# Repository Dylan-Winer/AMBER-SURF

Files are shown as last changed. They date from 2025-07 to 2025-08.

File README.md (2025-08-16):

# AMBER-SURF
Repository hosting project files as part of my Summer Undergraduate Research Fellowship (SURF) 2025 project within the AMBER Lab at Caltech.

## Mechanical Components & Assembly

This section covers the physical build of the foot modules and begins exactly where the right-foot assembly was left off.

---

### Complete the Right Foot: Rubber Sole & Adhesive Nuts

1. **Get the sole DXF**
   - Download `sole_base.DXF` from this repo:  
     https://github.com/Dylan-Winer/AMBER-SURF/blob/main/SolidWorks-CAD/G1_Integration/DXF_G1_3/sole_base.DXF

2. **Cut the rubber sole**
   - Acquire **1/8" thick rubber** sheet.
   - **Waterjet** cut the sole using `sole_base.DXF`. Deburr/trim if needed for a clean perimeter.

3. **Bolt the remaining hardware**
   - From the bag labeled **“4/40 BOLTS & SPACERS”**, locate the **four remaining adhesive nuts**, **4-40 bolts**, and **spacers**.
   - Install these in the positions on the **right foot** where bolts are currently missing. Snug the 4-40 bolts; don’t over-torque.
   - There are through-holes cut into the cable channels on both the heel connectors. Use these to fit an allen key through. You may need to push the cables out of the way with the allen key.

4. **Bond the adhesive nuts to the rubber**
   - Remove the rubber sole; place a small, even bead of **Gorilla Glue** *or* a suitable **epoxy** on the **underside of all 8 adhesive nuts**.
   - Press the **waterjet rubber sole** onto the adhesive nuts with **even pressure**. Using a **vise** to hold the foot makes this easier; protect surfaces with scrap pads.
   - **Cure per adhesive instructions.** (If using Gorilla Glue, lightly dampen the rubber for proper foaming; for epoxy, degrease both surfaces first.)

5. **Prep for base plate + toe installation**
   - **Unscrew** the four **4-40 bolts & spacers** that mount the **heel connector** to the foot so the **right foot matches the left**.
   - The **heel must come off** so the **base plate and toe** can be **slid on from the front**.

> ✅ Quick checklist  
> - [ ] Rubber sole waterjet and is clean  
> - [ ] All 8 adhesive nuts bonded and cured  
> - [ ] Heel connector hardware removed (right foot)  
> - [ ] Fit check: base plate + toe can slide on from the front

---

### Install Each Module (Left & Right Feet)

1. **Slide-on fit**
   - **Slip the G1 foot** through the **toe cover** until the bottom of the G1 foot is **fully seated** on the **top of the bottom base plate**.
   - Verify the **toe and heel bumpers** **fully enclose** the foot with uniform contact.

2. **Reinstall heel hardware**
   - Cover the heel of the G1 with the **heel mounts**.
   - **Screw the four 4-40 bolts + spacers** into the **four heel-mount holes**. Tighten evenly in a cross pattern until snug.

3. **Cable & strain relief**
   - Route cables cleanly along edges and through any provided channels. Add **strain relief** (zip ties/adhesive anchors) to protect connectors and solder joints.

4. **USB to host**
   - Connect **micro-USB** from **each foot module** to the computer. In practice you’ll likely use **USB extension cables** plus **90° micro-USB cables** to keep a low profile.

5. **Proceed to logging**
   - Follow the **Arduino/CoolTerm** instructions in the previous section to set **per-foot baud rates** and **capture data**.

# AMBER Lab SURF 2025 — G1 Foot Sensing Module

High-rate (1000 Hz) force + IMU logging for the Unitree G1 humanoid foot.  
The following contains Teensy 4.1 usage notes to capture synchronized FSR forces and MPU-6050 orientation/gyro data to CSV via CoolTerm.

---

## TL;DR (How to run & log)

1. **Install & open CoolTerm.**
2. **Connect the Teensy (USB).**
3. In CoolTerm: **Connection → Options…**
   - **Port:** select the COM port associated with your Teensy.
   - **Baudrate:** set to the same value used in firmware `Serial.begin(BAUDRATE)` (defaults shown in the code below are `2,000,000`).
   - Click **OK**.
4. Click **Connect**.
5. Start file logging: **Connection → File Capture → Start…**
   - Choose a folder, **create/name a `.txt` file**, click **Save**.
6. In the CoolTerm terminal, press **`s`** to **start** the program (CSV header prints once).
7. **Run your G1 test** (walk/stance as needed).
8. Press **`x`** to **stop** the program.
9. Stop file logging: **Connection → File Capture → Stop**.

> **Left vs Right foot**  
> You will run **two Teensies** (left/right) at **different baud rates** to avoid USB bandwidth contention and to keep ports distinct.  
> - Edit `Serial.begin(BAUDRATE)` in each foot’s firmware (e.g., Left `2,000,000`, Right `1,500,000`).  
> - In CoolTerm, pick the matching COM port and set the **Baudrate** accordingly for each run.

---

## Data format (CSV columns)

When logging is active, the firmware prints:
time_s,FSR1_N,FSR2_N,FSR3_N,FSR4_N,qw,qx,qy,qz,gx_rad_s,gy_rad_s,gz_rad_s

- **time_s** — seconds since you pressed `s`
- **FSR*_N** — force in Newtons after per-sensor linear calibration and dead-zone/zero-clipping (<2 N → 0)
- **qw..qz** — unit quaternion from Mahony filter
- **g*_rad_s** — body-frame gyro rates (rad/s) derived from RAW with offsets & scale

---

## Hardware overview

- **Controller:** Teensy 4.1 (3.3 V logic)
- **FSRs:** 4× FlexiForce A201 (per-sensor linear calibration applied)
- **IMU:** MPU-6050
- **Loop rate:** 1000 Hz fixed tick (1 ms)

---

## Build & Flash (Teensy 4.x)

1. Open this repo’s firmware in **Arduino IDE** or **Arduino CLI** with **Teensyduino** installed.
2. Select **Board: Teensy 4.0/4.1** and the correct **Port**.
3. (Optional) Adjust:
   - `Serial.begin(BAUDRATE)` for your left/right feet.
   - FSR calibration `slope[]` and `intercept[]`.
   - Mahony gains `Kp`, `Ki`.
4. **Upload**.

## 3) Analyze Data (Python)

Program link (full script):  
**➡️ https://github.com/Dylan-Winer/AMBER-SURF/blob/main/Python_Code/G1_Data_Analysis/Force_Plot_Final.py**

**Use it like this:**
- Replace `file_path` with your CoolTerm **.txt/.csv** path.
- Set `t_start_s` and `t_end_s` (easiest way to focus on a window; set `0` to analyze everything).
- Run the script to get **plots** and **replay videos** (MP4 if FFmpeg available; otherwise GIF).
- Don’t need outputs? Comment out the plot sections and/or the `make_replay_video(...)` calls.

**Expected columns** in the file:
time_s,FSR1_N,FSR2_N,FSR3_N,FSR4_N,qw,qx,qy,qz,gx_rad_s,gy_rad_s,gz_rad_s

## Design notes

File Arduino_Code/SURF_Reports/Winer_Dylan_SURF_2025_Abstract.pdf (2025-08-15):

Toward Contact-Aware Humanoid Locomotion: A Modular Foot Sensing Platform Dylan Winer
Mentors: Aaron Ames, Sergio Esteban, and Adrian Ghansah

Stable locomotion in humanoid robots requires accurate knowledge of foot-ground interaction forces, yet existing systems often lack integrated, distributed foot sensing and typically rely on flat, rigid feet that omit the heel-toe rolling found in human gait. To address this, we developed a modular sensing platform with a passive toe mechanism for a new humanoid robot in the AMBER Lab. The system integrates FlexiForce™ force-sensitive resistors (FSRs) amplified through non-inverting op-amp circuits, inertial measurement units (IMUs), and magnetic encoders. Each FSR is individually calibrated to linearly interpolate force from analog voltage output. A custom 4-layer PCB interfaces with a Teensy 4.1 microcontroller, supporting analog readout, 16 status LEDs, dual IMU input, and a PWM-based encoder for passive toe angle measurement. The standalone mechanical design includes toe and midfoot segments, torsional spring toe actuation, a waterjet-cut rubber sole, and helical insert fasteners. All components are mounted to a modular foot structure appended to the Unitree G1 humanoid for initial testing. Final integration will enable measurement of distributed ground reaction forces, segment orientations, and joint angles during walking. This modular platform offers a scalable foundation for contact-aware control to improve future humanoid locomotion and manipulation.

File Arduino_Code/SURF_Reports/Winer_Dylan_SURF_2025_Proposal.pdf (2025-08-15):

SURF 2025 Proposal: Improving Humanoid Locomotion via Advanced Foot Sensing

Introduction/Background

This research project investigates the enhancement of bipedal robot locomotion by incorporating multi-contact foot behavior through the advancement of foot sensing capabilities. Current limitations in bipedal robotics, such as restricted agility and efficiency, stem from simplified models that often neglect the nuanced dynamics of human walking, which involve multi-contact interactions between the foot and the ground (e.g., heel-toe rolling). This research addresses these limitations by drawing inspiration from human locomotion and developing novel control strategies that enable more natural and dynamic walking behavior.

Building upon the research conducted by Professor Ames and his group in the AMBER Lab, which has established a strong foundation in developing control strategies for bipedal robots using reduced-order models and hybrid systems theory, this project will explore how integrating more advanced foot sensors can improve model accuracy and enable more dynamic, human-like gait transitions. Specifically, various sensors of interest will be investigated, the existing foot design will be modified to integrate these sensors, and their impact on locomotion performance will be validated. The successful implementation of these advancements will lead to significant improvements in the stability, efficiency, and robustness of bipedal robots, with potential applications in humanoid assistance, disaster relief, and space exploration.

Objectives

This project aims to improve humanoid locomotion by integrating advanced foot sensing, enabling more natural and efficient multi-contact walking. To achieve this, ground reaction forces, contact locations, and foot orientation among others will be measured using pressure sensors, inertial measurement units (IMUs), capacitive sensors, and various others under diverse walking conditions. The starting assumption is that the current humanoid robot has a rigid foot featuring toe and ankle mechanisms without sensing capabilities, limiting its ability to adapt to uneven terrain and dynamic motion. A successful outcome will involve designing and implementing a novel foot structure that seamlessly integrates these sensors; developing a data-driven model of multi-contact foot behavior utilizing sensor data collected from the robot; integrating sensor feedback into a control framework to adapt robot behavior in real-time based on observed interactions; and evaluating the enhanced robot’s performance through metrics such as energy consumption, step length, and robustness to perturbations. Success will be determined by the effective integration and validation of the sensors, the accuracy of the foot behavior model, and demonstrated improvements in robotic locomotion.

Approach

To accomplish the project objectives, a structured, 10-week approach will be followed inspired by previous research in bipedal robotics, with key milestones outlined below:

1. Sensor Exploration (Weeks 1-2): Various sensors—pressure sensors, IMUs, capacitive sensors, and more—will be experimented with to understand their behavior and how to best integrate them into the foot. This hands-on exploration will inform the selection and analysis methods for each sensor type.
2. Mechanical Design (Weeks 3-4): The foot design will be modeled and modified in SolidWorks® to integrate the chosen sensors. This process will ensure the foot can support multi-contact interactions, enabling more advanced locomotion than flat-foot sensing.
3. Sensor Integration (Weeks 5-7): The selected sensors will be integrated into the foot structure, focusing on ensuring accurate measurements of foot-ground interactions, allowing for state-of-the-art motion including stair climbing and running.
4. Performance Validation (Weeks 8-9): The robot will undergo a series of tests to evaluate the effectiveness of the sensor-integrated foot. These tests will assess the foot’s ability to adapt to different terrain conditions and its overall locomotion capabilities.
5. Evaluation and Adjustments (Week 10): In the final week, the foot’s performance will be thoroughly assessed, and any necessary adjustments will be made to optimize its functionality, ensuring it is capable of humanoid and dynamic motion.

Sensor integration will be particularly challenging due to the diverse signal types from different sensors, requiring careful calibration and data fusion. To address this, insights will be leveraged from the LIDAR Lab and Professor Zhao’s work on multi-modal contact sensing and terrain classification to optimize sensor selection and data processing strategies. Sergio Esteban, serving as the project mentor, will be consulted along with other AMBER Lab students to refine the integration process and troubleshoot issues collaboratively. The basic foot and humanoid robot will be inherited from the lab, but sensors, testing equipment, and facilities will be needed to measure the foot’s effectiveness. For example, an Instron machine may be utilized to cyclically assess the sensor-equipped foot during validation testing. An Arduino or similar platform will be utilized for sensor integration and software like Simulink will be used for foot and sensor control. The role will involve collaboration with Adrian Ghansah, who is focused on the development of 3D humanoid robots. This project’s completion will not depend on others, but the overall integration and validation of the robot will rely on progress from two students overseeing structural analysis and manufacturability.

Work Plan

Task | Start Date | End Date
Sensor Exploration | Week 1 | Week 2
Mechanical Design | Week 3 | Week 4
Sensor Integration | Week 5 | Week 7
Performance Validation | Week 8 | Week 9
Evaluation and Adjustments | Week 10 | Week 10
Final Technical Paper & Presentation | To be determined | Week 10

References

[1] X. Guo et al., “Soft Foot Sensor Design and Terrain Classification for Dynamic Legged Locomotion,” IEEE International Conference on Soft Robotics (RoboSoft), pp. 550–557, May 2020, doi: https://doi.org/10.1109/robosoft48309.2020.9115990.
[2] T. Tyler, V. Malhotra, A. Montague, Z. Zhao, F. L. Hammond, and Y. Zhao, “Integrating Reconfigurable Foot Design, Multi-modal Contact Sensing, and Terrain Classification for Bipedal Locomotion,” IFAC-PapersOnLine, vol. 56, no. 3, pp. 523–528, 2023, doi: https://doi.org/10.1016/j.ifacol.2023.12.077.
[3] M. Dai, J. Lee, and A. D. Ames, “Multi-Domain Walking with Reduced-Order Models of Locomotion,” 2022 American Control Conference (ACC), pp. 2830–2837, Jul. 2024, doi: https://doi.org/10.23919/acc60939.2024.10644270.
[4] H. Zhao, A. Hereid, W. Ma, and A. D. Ames, “Multi-contact bipedal robotic locomotion,” Robotica, vol. 35, no. 5, pp. 1072–1106, Dec. 2015, doi: https://doi.org/10.1017/s0263574715000995.

Discussions with AMBER Lab PhD students Adrian Ghansah and Sergio Esteban emphasized that every biomechanical example of locomotion relies on foot sensing for stability and adaptability, but current systems operate with limited sensing capabilities. Their insights on ongoing efforts, including the development of a new bipedal robot with a dedicated toe mechanism, informed the direction of this project.

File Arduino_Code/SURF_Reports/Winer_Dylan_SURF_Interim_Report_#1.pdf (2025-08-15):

Winer 1

Researcher: Dylan Winer

PI: Professor Aaron Ames

Mentor: Sergio Esteban

Date: June 27, 2025

SURF 2025 Interim Report #1

Motivation and Background
Understanding the ground reaction forces and moments at a humanoid robot's foot is essential for achieving robust, adaptable, and dynamically stable locomotion across varied terrains. This information enables control algorithms to react appropriately to foot-ground interactions, such as uneven loading between heel and toe or early loss of contact during a step. My project focuses on the development of a modular tactile sensing foot that can quantify such force distributions during walking. The long-term goal is to develop a lightweight, low-cost, replaceable sensor module that outputs real-time tactile data, contributing to the broader
AMBER Lab initiative of designing a full humanoid robot platform by the end of the summer. This work ties into the broader research within the AMBER Lab, which investigates hybrid systems theory and optimization-based control for robotic locomotion [1, 2]. Previous work has demonstrated that ground contact forces, represented as external reaction terms λ in the Lagrangian formulation, play a central role in multi-domain bipedal walking models [2]. Several prior sensor designs have been proposed to estimate these forces, including MEMS barometric sensor arrays [3], multimodal contact sensing with reconfigurable feet [4, 5], and integrated force-torque sensors [6]. These systems inspire the sensing strategies explored in this project.

Problem and Methods
The core problem is designing and integrating a sensor system that can estimate spatially distributed ground forces under the foot while remaining modular, affordable, and lightweight. Commercial force-torque sensors and pressure mats are often prohibitively expensive or unfit for onboard integration. Therefore, our approach is to prototype with Force-Sensitive Resistors (FSRs) and mechanical push buttons due to their simplicity, availability, and ease of integration. While these sensors have limitations in accuracy and drift, they offer a scalable platform for preliminary force localization, edge detection, and binary contact confirmation.
We are exploring multiple sensing modalities: barometric pressure sensors for distributed sensing, FSRs for localized force detection, and rugged push buttons for binary heel/toe contact validation. The system is being prototyped using a Teensy 4.0 microcontroller and inverting op-amp circuits for signal conditioning. Our initial integration pathway uses analog inputs and voltage dividers, with plans to transition to multiplexed digital buses (e.g., I²C or CAN) for final integration into the robot. In parallel, we are developing a custom PCB using KiCAD and JLCPCB manufacturing constraints to create a robust, soldered version of the prototype circuit. Mechanically, the sensors are being embedded into a multilayer sole that includes silicone rubber for load distribution and protection, with manufacturer-provided pucks to concentrate forces.

Progress
Significant progress has been made across sensor selection, prototyping, mechanical design, and PCB development. We began with a review of prior foot sensor integrations, including MEMS barometers, FSRs, and six-axis force/torque sensors. We then prototyped a voltage divider circuit using Interlink FSR 406 sensors and calibrated the force-resistance relationship through known loads (Figures 1-2). The derived relationship followed a log-log
trend: | (Figure 3), enabling real-time force estimation from analog readings.
These signals were visually validated with LEDs and displayed on Arduino IDE’s plotter.
| We created CAD models of the force sensors, load concentrator pucks, and a multilayer
foot assembly that includes recesses and cable routing (Figures 4-9). For binary detection, we wired pushbuttons to Teensy pins and assessed their behavior under simulated footfalls. Additionally, we explored edge detection by taping FSR strips to the front and rear of a Unitree G1 Humanoid robot foot (Figure 10), confirming that 1 N was a reasonable threshold for contact events. We then designed a two-FSR PCB prototype in KiCAD with surface-mounted LEDs for feedback, Teensy header footprints, resistors, and analog input wiring (Figures 11-15). We then created the manufacturing files in accordance with JLCPCB constraints. Finally, we designed a passive toe mechanism for enhanced contact area, referencing both previous AMBER designs and published work (Figures 16-17). The front toe segment rotates about a shaft constrained radially by two bushings and axially by shaft collars. A 120° torsional spring provides the restoring moment. It remains preloaded to ensure the two segments are parallel while the toe is not activated. All 3D prints have been fabricated and parts ordered for initial assembly.

Challenges and Anticipated Problems
| One major challenge is the high cost and limited modularity of commercial force-torque
sensors. Many high-performance options cost $3,000–$10,000 and must be installed at the ankle, complicating direct foot sensing. Similarly, commercial pressure mats from AMTI or Kistler are prohibitively expensive for long-term use, though we identified an affordable $400 force plate from Vernier for validation purposes, which we may pursue further.
| Another challenge involves the complexity of custom MEMS barometer sensors. These
require delicate mechanical modifications, vacuum-cast encapsulation, and custom PCB designs with multiplexers. While promising, these systems demand greater resources and will be explored later in the project. PCB design also presented difficulties, as we initially began in Autodesk Eagle before switching to KiCAD due to future deprecation. Learning KiCAD workflows, adhering to JLCPCB manufacturing rules, and generating valid Gerber files required careful attention. The prototype PCB will be soldered and evaluated in the coming week.
| Moving forward, we anticipate challenges in validating the sensor outputs against known
force data, especially under dynamic walking conditions. Signal noise, mechanical stress shielding, and sensor drift may also introduce errors. However, our modular design approach and layered validation strategy, using both internal sensors and potentially an external plate, position us well to continue iterating toward a deployable foot module.

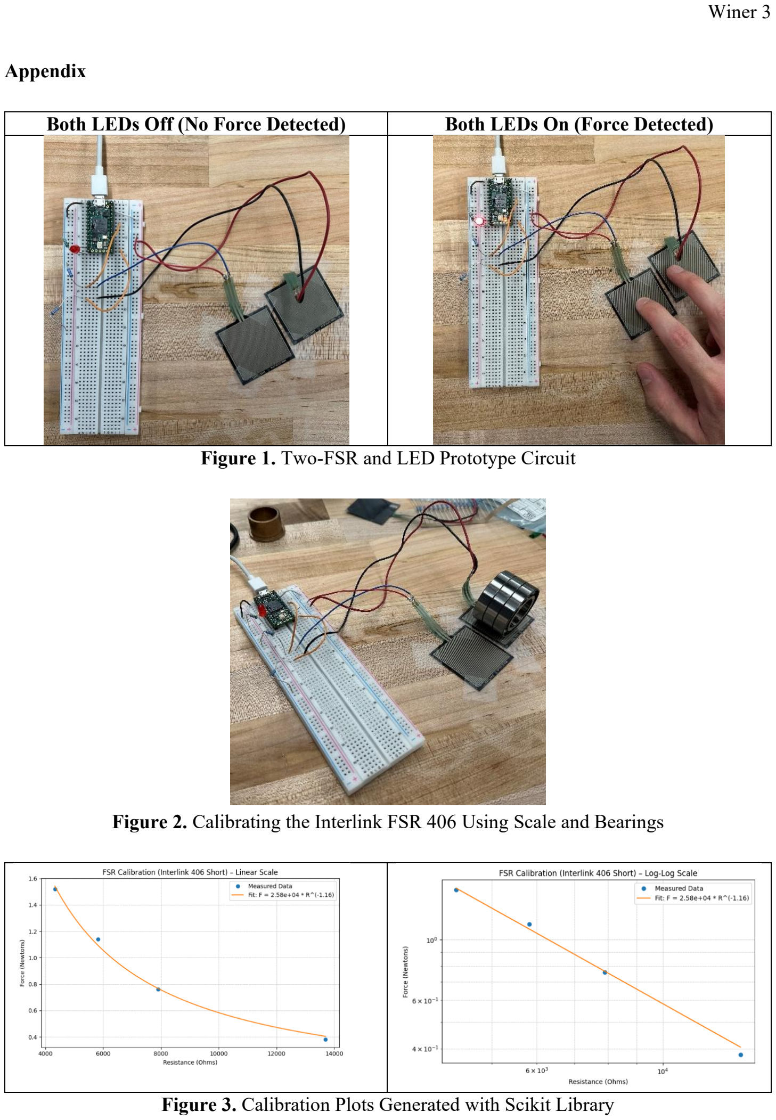
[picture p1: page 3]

Appendix

Both LEDs Off (No Force Detected) | Both LEDs On (Force Detected)

Figure 1. Two-FSR and LED Prototype Circuit

Figure 2. Calibrating the Interlink FSR 406 Using Scale and Bearings

Figure 3. Calibration Plots Generated with Scikit Library

Figure 4. CAD Model of FlexiForce A201 Sensor

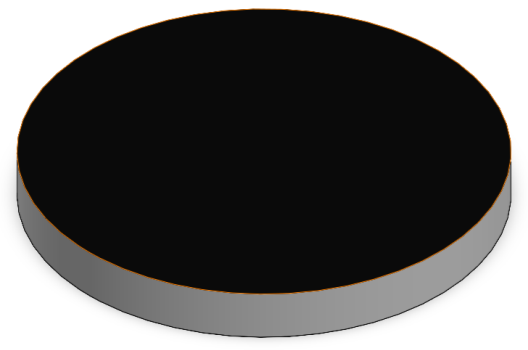
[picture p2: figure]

Figure 5. CAD Model of FLXLC-A Puck for A201 Sensor

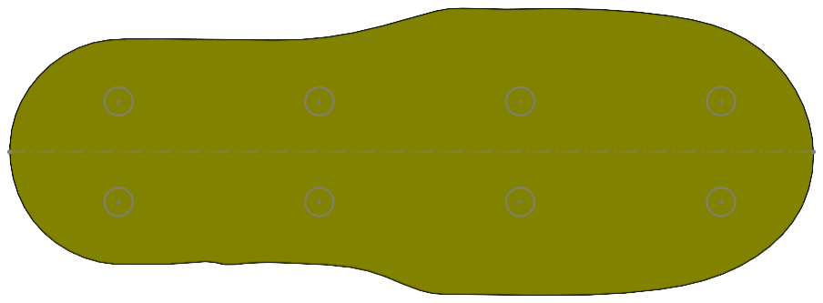
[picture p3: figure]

Figure 6. CAD Model of Top of Preliminary Sensing Module Assembly

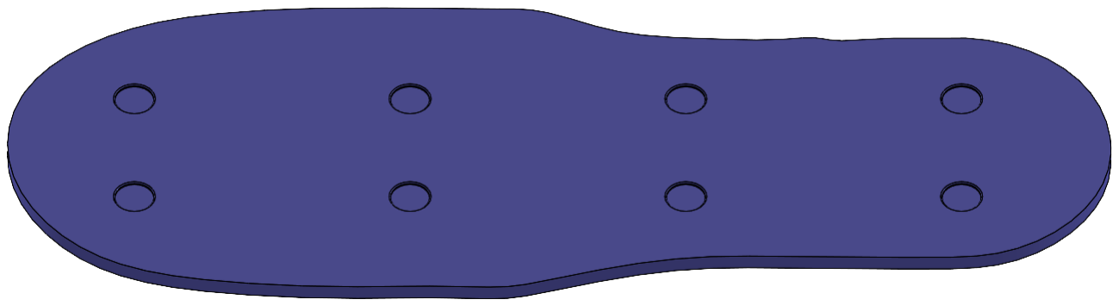
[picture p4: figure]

Figure 7. CAD Model of Bottom of Preliminary Sensing Module Assembly

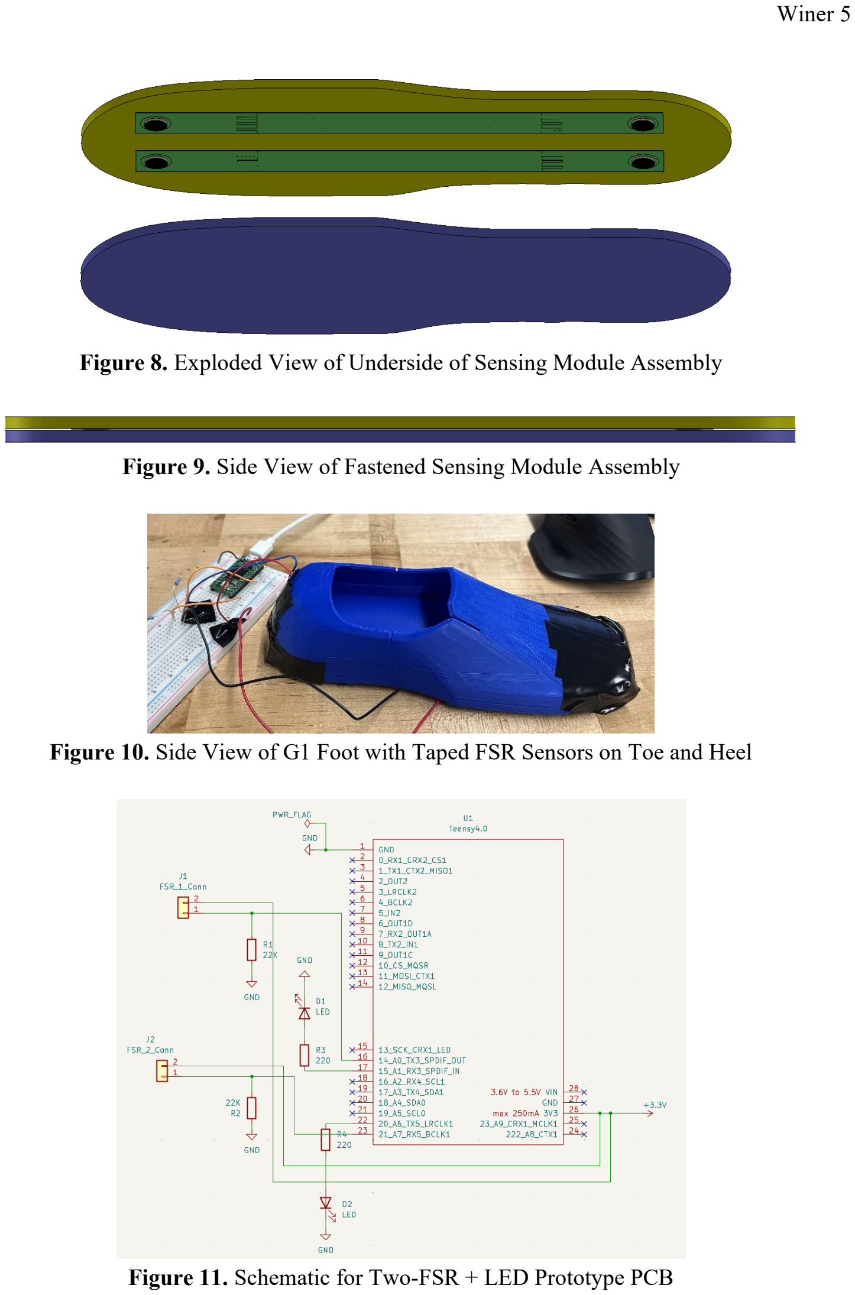
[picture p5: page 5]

Figure 8. Exploded View of Underside of Sensing Module Assembly

Figure 9. Side View of Fastened Sensing Module Assembly

Figure 10. Side View of G1 Foot with Taped FSR Sensors on Toe and Heel

Figure 11. Schematic for Two-FSR + LED Prototype PCB

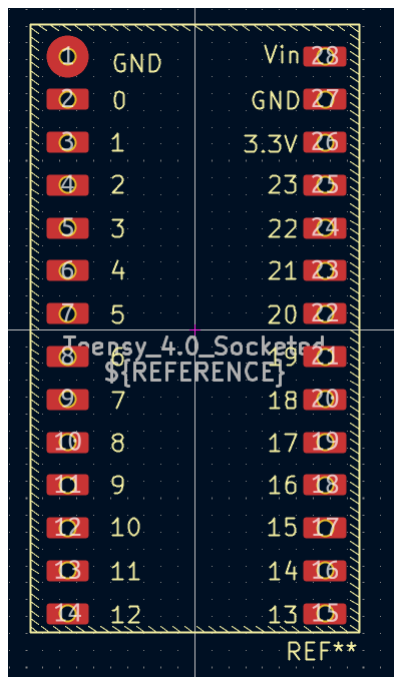
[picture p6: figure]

Figure 12. Custom Footprint Created for Teensy Through-Holes

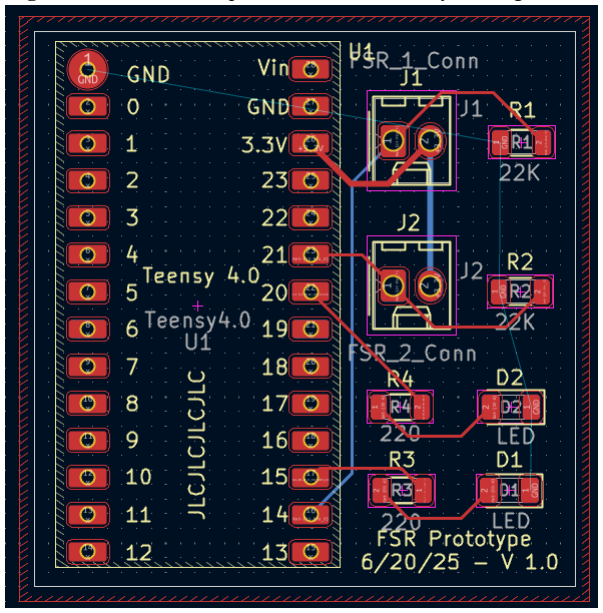
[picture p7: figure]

Figure 13. FSR Prototype PCB Sketch with Traces and Components

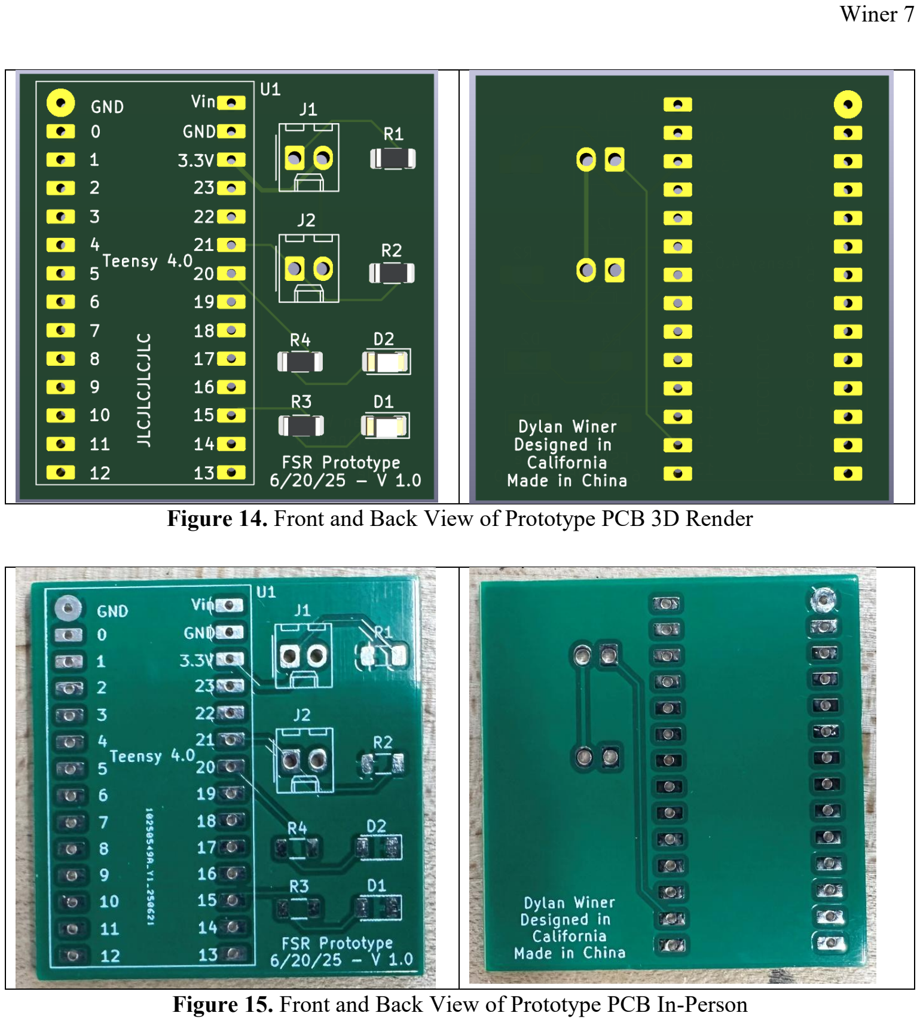
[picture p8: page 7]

Figure 14. Front and Back View of Prototype PCB 3D Render

Figure 15. Front and Back View of Prototype PCB In-Person

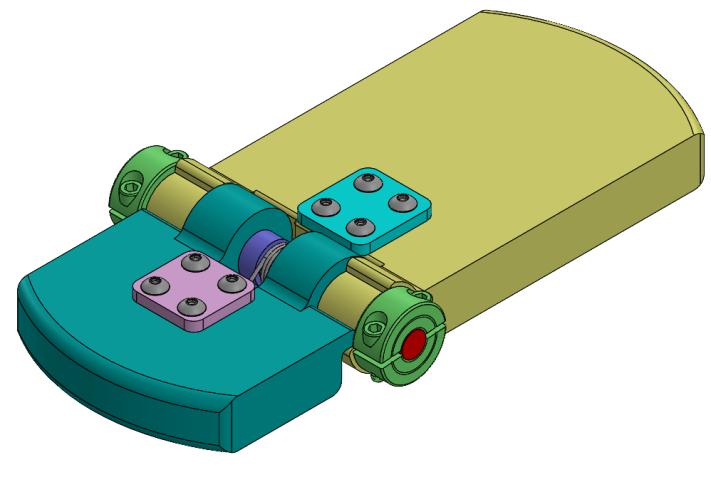
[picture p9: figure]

Figure 16. Isometric View of Prototype Passive Toe Assembly

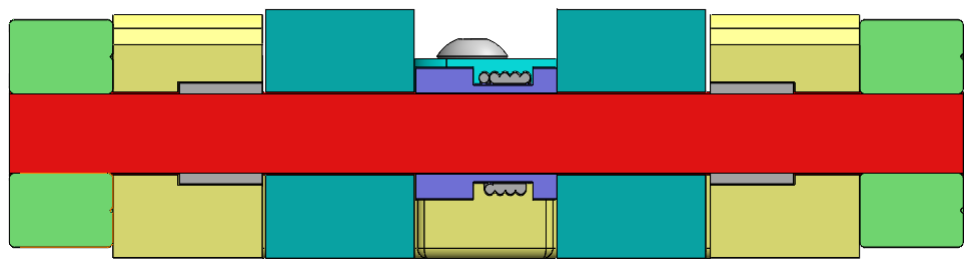
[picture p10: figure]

Figure 17. Cross-Section View of Center Shaft, Segments, Bushings, and Spring

References

[1] M. Dai, J. Lee, and A. D. Ames, “Multi-Domain Walking with Reduced-Order Models of Locomotion,” 2022 American Control Conference (ACC), pp. 2830–2837, Jul. 2024, doi: https://doi.org/10.23919/acc60939.2024.10644270.
[2] H. Zhao, A. Hereid, W. Ma, and A. D. Ames, “Multi-contact bipedal robotic locomotion,” Robotica, vol. 35, no. 5, pp. 1072–1106, Dec. 2015, doi: https://doi.org/10.1017/s0263574715000995.
[3] X. Guo et al., “Soft Foot Sensor Design and Terrain Classification for Dynamic Legged Locomotion,” pp. 550–557, May 2020, doi: https://doi.org/10.1109/robosoft48309.2020.9115990.
[4] T. Tyler, V. Malhotra, A. Montague, Z. Zhao, F. L. Hammond III, and Y. Zhao, “Integrating Reconfigurable Foot Design, Multi-modal Contact Sensing, and Terrain Classification for Bipedal Locomotion,” IFAC-PapersOnLine, vol. 56, no. 3, pp. 523–528, 2023, doi: https://doi.org/10.1016/j.ifacol.2023.12.077.
[5] Risto Koiva, T. Schwank, G. Walck, M. Meier, R. Haschke, and H. Ritter, “Barometer-based Tactile Skin for Anthropomorphic Robot Hand,” Oct. 2020, doi: https://doi.org/10.1109/iros45743.2020.9341691.
[6] K. Fondahl et al., “An adaptive sensor foot for a bipedal and quadrupedal robot,” Jun. 2012, doi: https://doi.org/10.1109/biorob.2012.6290735.

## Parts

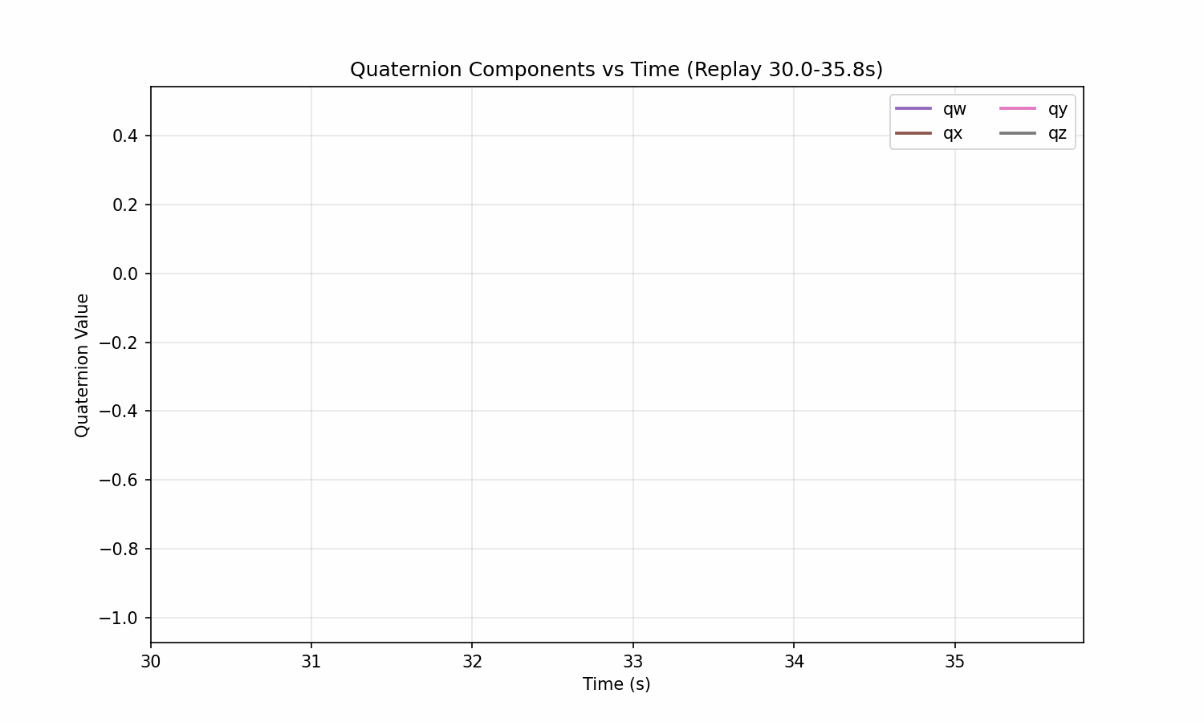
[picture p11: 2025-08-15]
Python_Code/G1_Data_Analysis/G1-Post_Animations/30_35-8_seconds/quaternion_components_replay_30.0-35.8s.gif

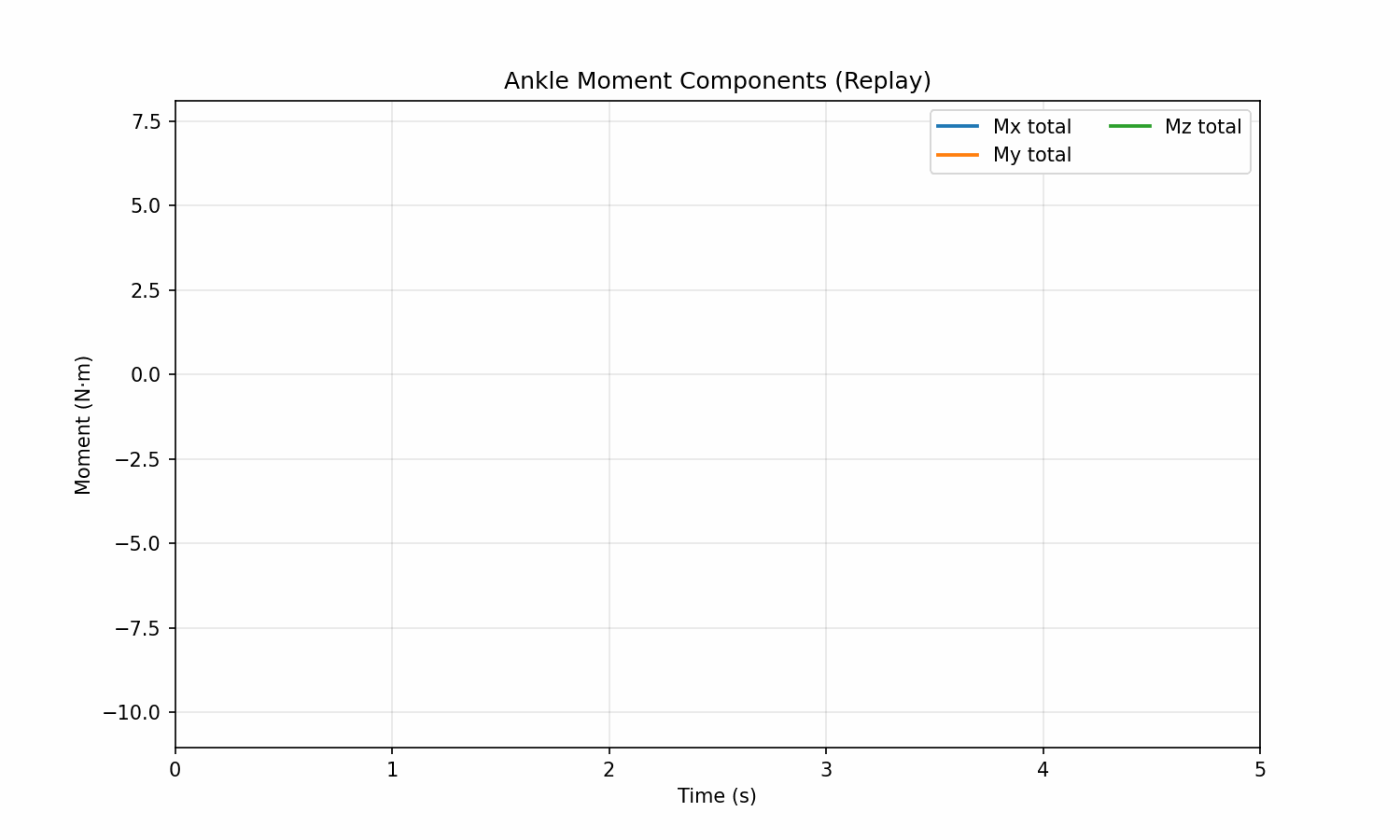
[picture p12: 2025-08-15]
Python_Code/G1_Data_Analysis/G1-Post_Animations/0_5_seconds/moments_components_replay.gif

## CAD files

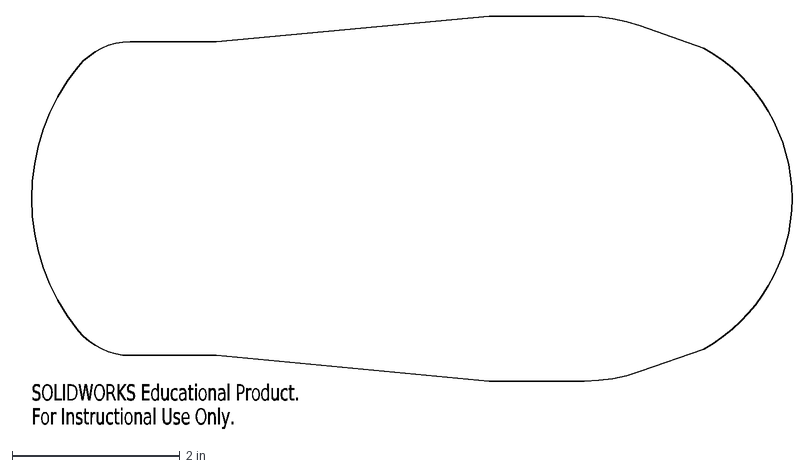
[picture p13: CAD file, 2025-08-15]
SolidWorks-CAD/G1_Integration/DXF_G1_3/sole_base.DXF
SOLIDWORKS Educational Product.
For Instructional Use Only.

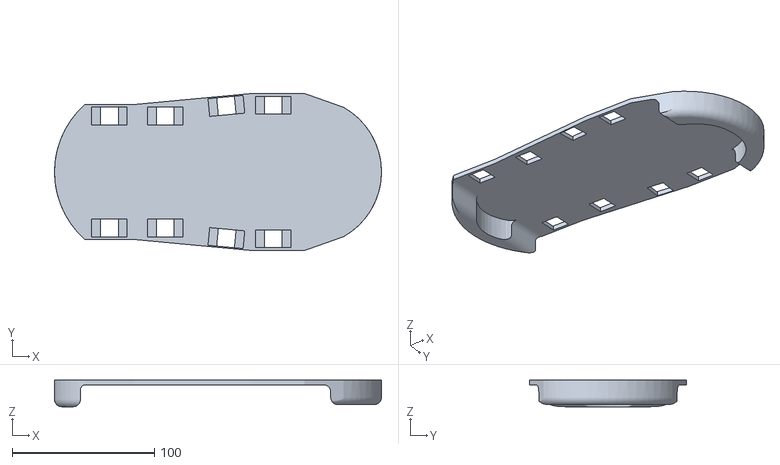
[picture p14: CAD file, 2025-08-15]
SolidWorks-CAD/G1_Integration/G1_2/sole_mid_V2.STL
230.2 x 110.5 x 18.7

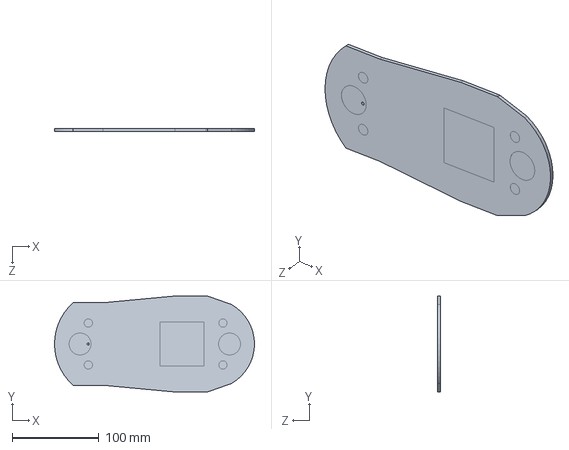
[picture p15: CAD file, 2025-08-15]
SolidWorks-CAD/G1_Integration/G1_Dylan_Pack_And_Go/sole_base.SLDPRT
230.2 x 110.5 x 3.18 mm

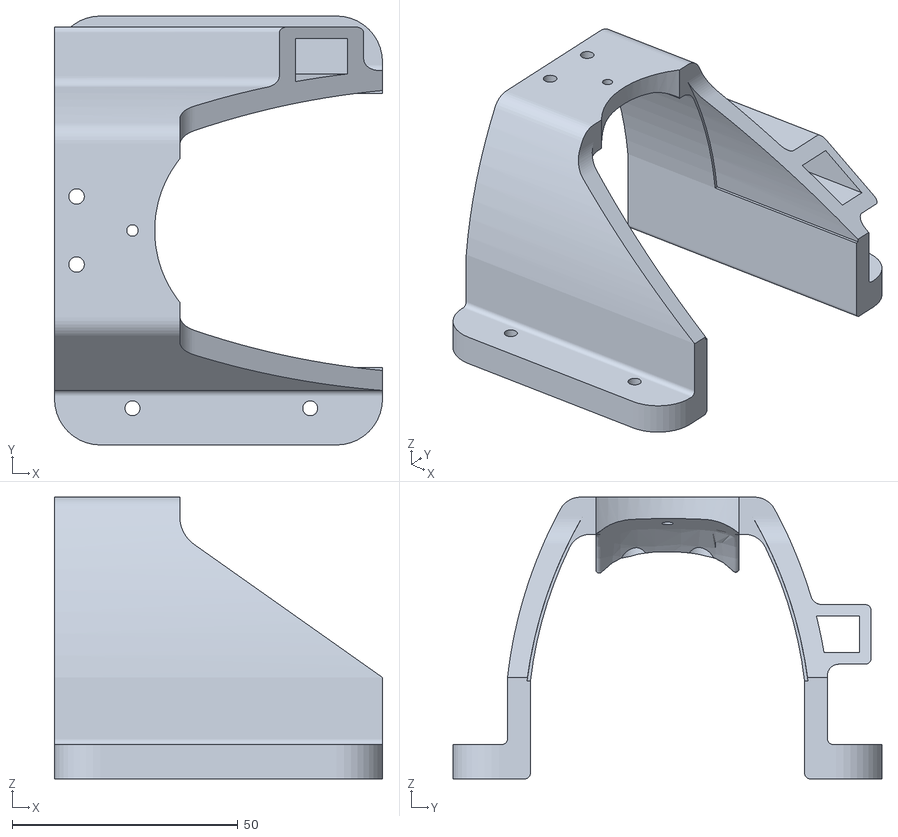
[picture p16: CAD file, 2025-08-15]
SolidWorks-CAD/G1_Integration/STLS_G1_1/mid-back.STL
72.6 x 95.0 x 62.4

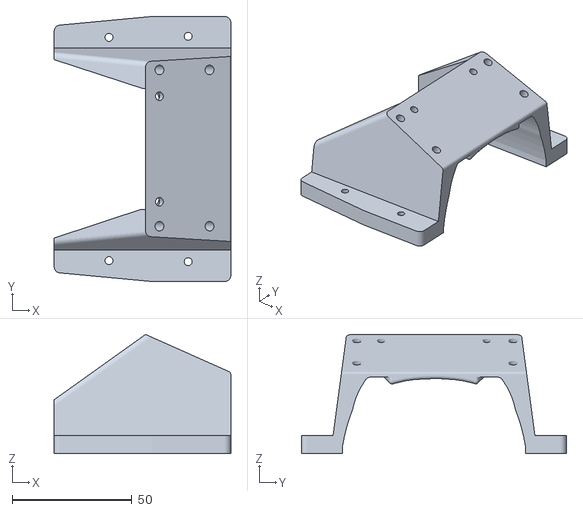
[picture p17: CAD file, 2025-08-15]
SolidWorks-CAD/G1_Integration/STLS_G1_3/mid-front-right.STL
73.7 x 110.5 x 49.7

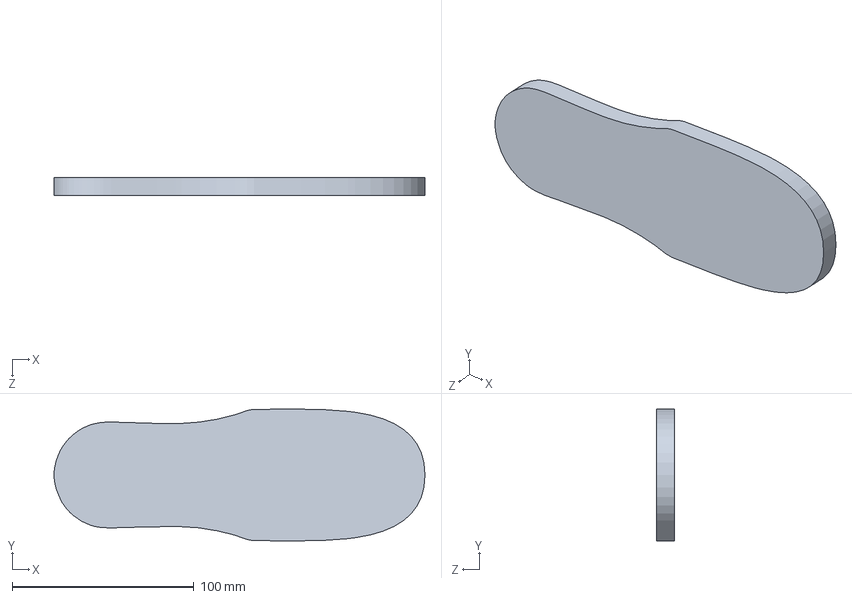
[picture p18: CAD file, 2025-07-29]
SolidWorks-CAD/Prototype1/Thicken1.SLDPRT
204.3 x 72.5 x 9.86 mm

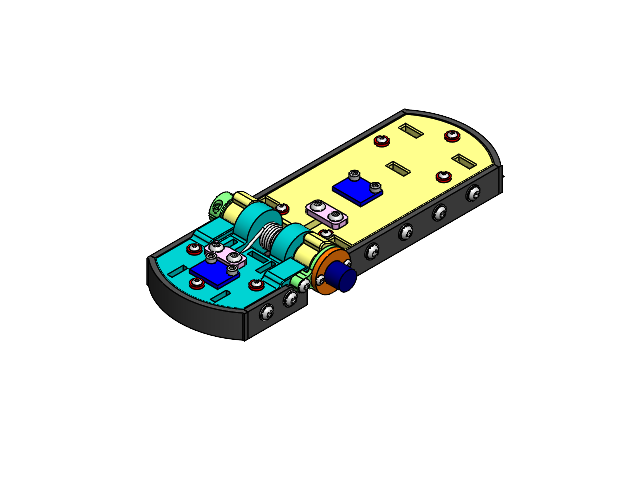
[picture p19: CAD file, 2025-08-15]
SolidWorks-CAD/Toe_Prototype_2/Passive_Toe_2.SLDASM
Heel_Midfoot_2
Shaft_2
Toe_Segment_2
6436K32_Clamping Two-Piece Shaft Collar
2867T41_Corrosion-Resistant Sleeve Bearing x 2
9271K641_Torsion Spring
Spring_Sleeve_2
Top-Plate-Midfoot_2-2
Toe_Rubber
Heel_Midfoot_Rubber
A201_2 x 4
FLXLC-A x 8
93512A110_Stainless Steel Narrow-Base Adhesive-Ready Nuts x 8
A502
A401 x 2
A401_Puck x 2
A502_Puck
Top-Plate-Heel_2-2
SideRubberToe
SideRubberToeOG
FrontBackRubber x 2
SideRubberHeel
SideRubberHeelEnc
91732A656_Stainless Steel Helical Insert x 17
92095A192_Button Head Hex Drive Screw x 17
Spacer1 x 6
Spacer2 x 2
92949A811_18-8 Stainless Steel Button Head Hex Drive Screw x 8
93475A230_18-8 Stainless Steel Washer x 12
magnet_hub
base_mount
base
90593A001_Black-Oxide Steel Hex Nut x 6
92095A181_Button Head Hex Drive Screw x 2
MPU-6050 x 2
91290A115_Alloy Steel Socket Head Screw x 4

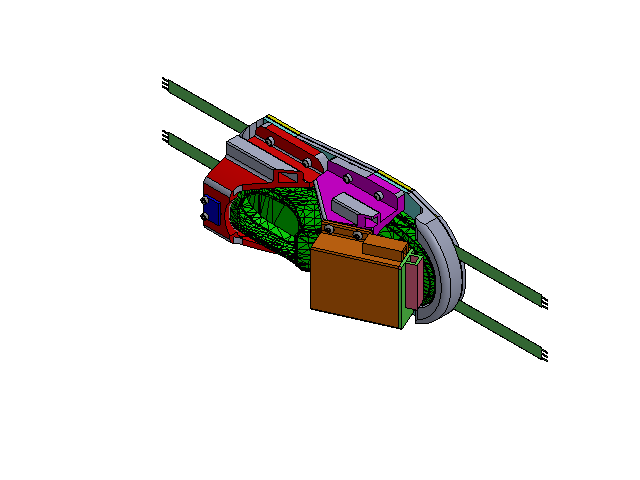
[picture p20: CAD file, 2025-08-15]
SolidWorks-CAD/G1_Integration/G1_Dylan_Pack_And_Go/g1-assembly-v2.SLDASM
g1_left_foot
sole_base
mid-back
A201_2 x 4
MPU-6050
A401_Puck x 3
FLXLC-A x 4
A502_Puck
93512A110_Stainless Steel Narrow-Base Adhesive-Ready Nuts x 8
92949A811_18-8 Stainless Steel Button Head Hex Drive Screw x 8
longSpacer x 8
91290A115_Alloy Steel Socket Head Screw x 4
90593A001_Black-Oxide Steel Hex Nut x 4
sole_mid
mid-front3
FSR_3_PCB
Rect_Spacer x 2
PCB_Cover
91732A656_Stainless Steel Helical Insert x 4
92095A192_Button Head Hex Drive Screw x 4
PCB_Cover_Plate

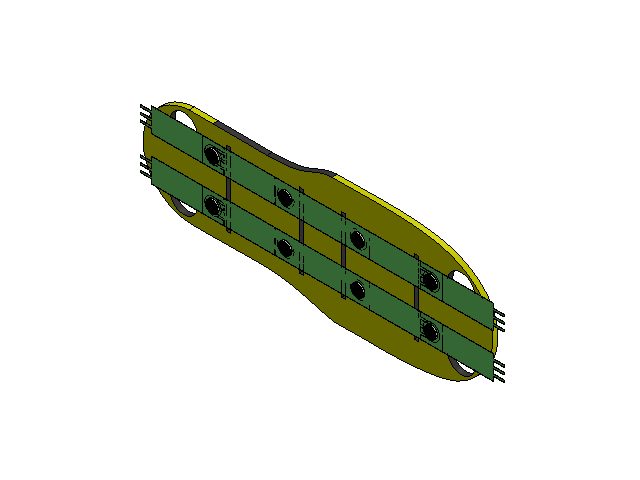
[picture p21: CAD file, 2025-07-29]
SolidWorks-CAD/Prototype1/Top-Foot.SLDASM
Rubber-Pad-Top
A201 x 8
FLXLC-A x 8

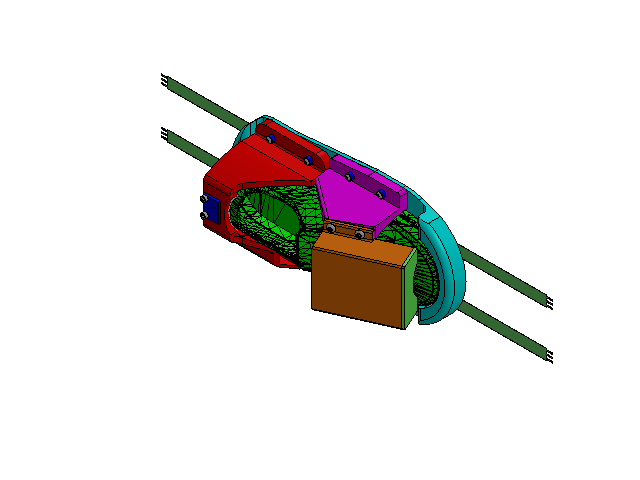
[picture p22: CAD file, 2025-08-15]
SolidWorks-CAD/G1_Integration/g1-assembly-v2.SLDASM
g1_left_foot
mid-back
A201_2 x 4
MPU-6050
A401_Puck x 3
FLXLC-A x 4
A502_Puck
93512A110_Stainless Steel Narrow-Base Adhesive-Ready Nuts x 8
92949A811_18-8 Stainless Steel Button Head Hex Drive Screw x 8
longSpacer x 8
91290A115_Alloy Steel Socket Head Screw x 4
90593A001_Black-Oxide Steel Hex Nut x 4
sole_mid
mid-front3
FSR_3_PCB
Rect_Spacer x 2
PCB_Cover
91732A656_Stainless Steel Helical Insert x 4
92095A192_Button Head Hex Drive Screw x 4
PCB_Cover_Plate

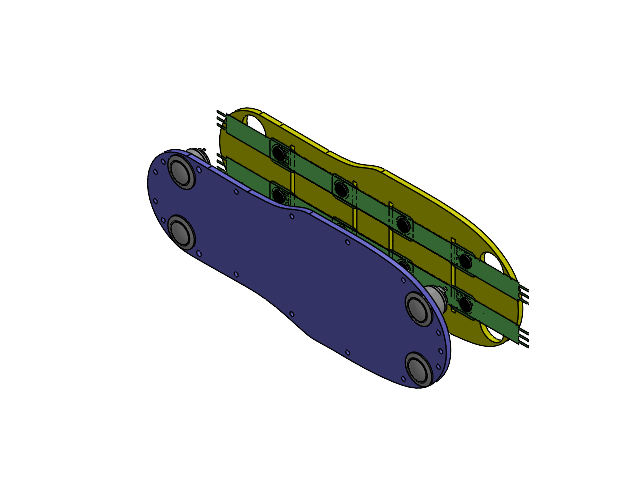
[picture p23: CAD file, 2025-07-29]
SolidWorks-CAD/Prototype1/Sensor-Assembly.SLDASM
Rubber-Pad
Rubber-Pad-Top
A201 x 8
FLXLC-A x 8
141_PV2S240xx x 4

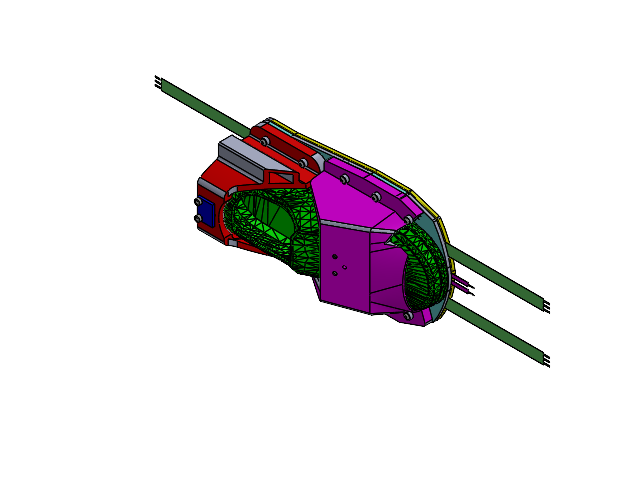
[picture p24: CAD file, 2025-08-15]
SolidWorks-CAD/G1_Integration/g1-assembly.SLDASM
g1_left_foot
sole_base
mid-back
A401 x 2
A201_2 x 4
MPU-6050
A401_Puck x 2
A502
FLXLC-A x 4
A502_Puck
93512A110_Stainless Steel Narrow-Base Adhesive-Ready Nuts x 10
92949A811_18-8 Stainless Steel Button Head Hex Drive Screw x 10
longSpacer x 10
91290A115_Alloy Steel Socket Head Screw x 2
90593A001_Black-Oxide Steel Hex Nut x 4
sole_mid
toeCombined

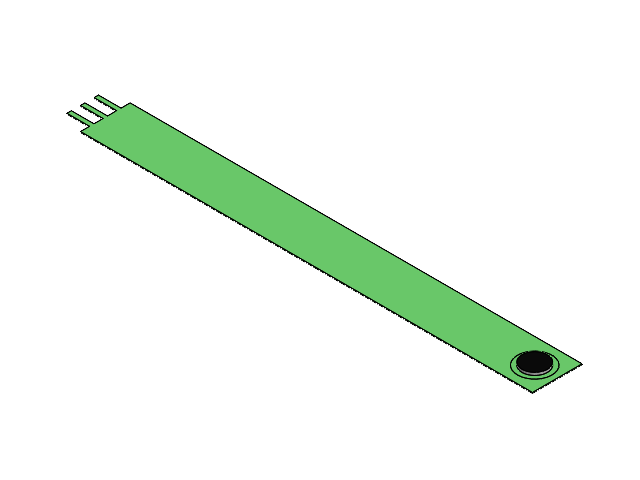
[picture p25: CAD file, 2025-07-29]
SolidWorks-CAD/Prototype1/A201_Puck.SLDASM
A201
FLXLC-A

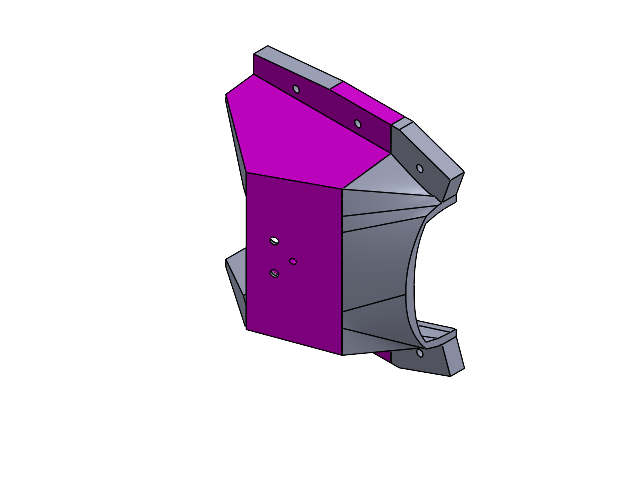
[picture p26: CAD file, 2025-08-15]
SolidWorks-CAD/G1_Integration/Assem2.SLDASM
mid-front3
toe-front

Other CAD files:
SolidWorks-CAD/G1_Integration/G1_Dylan_Step/g1-assembly-v2.STEP
SolidWorks-CAD/G1_Integration/G1_Dylan_Pack_And_Go/g1-assembly.SLDASM
SolidWorks-CAD/G1_Integration/Assem1.SLDASM
SolidWorks-CAD/G1_Integration/sole_mid.SLDPRT
SolidWorks-CAD/G1_Integration/90751A110_18-8 Stainless Steel Socket Head Screws.SLDPRT
SolidWorks-CAD/G1_Integration/FSR_3_PCB.SLDPRT
SolidWorks-CAD/G1_Integration/G1_Dylan_Pack_And_Go/90593A001_Black-Oxide Steel Hex Nut.SLDPRT
SolidWorks-CAD/G1_Integration/G1_Dylan_Pack_And_Go/91290A115_Alloy Steel Socket Head Screw.SLDPRT
SolidWorks-CAD/G1_Integration/G1_Dylan_Pack_And_Go/91732A656_Stainless Steel Helical Insert.SLDPRT
SolidWorks-CAD/G1_Integration/G1_Dylan_Pack_And_Go/92095A192_Button Head Hex Drive Screw.SLDPRT
SolidWorks-CAD/G1_Integration/G1_Dylan_Pack_And_Go/92949A811_18-8 Stainless Steel Button Head Hex Drive Screw.SLDPRT
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

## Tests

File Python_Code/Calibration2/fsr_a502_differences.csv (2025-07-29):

 | Δ Slope (%) | Δ Intercept (%)
A502 | 35.36757154670058 | 0.3083542586135342
FSR 1 | 0.0 | 0.0
FSR 2 | 15.355898836557794 | 0.28072114787285235
FSR 3 | 20.321792769045093 | 0.6395511124909617
FSR 4 | 29.679089993074037 | 0.878444216272834

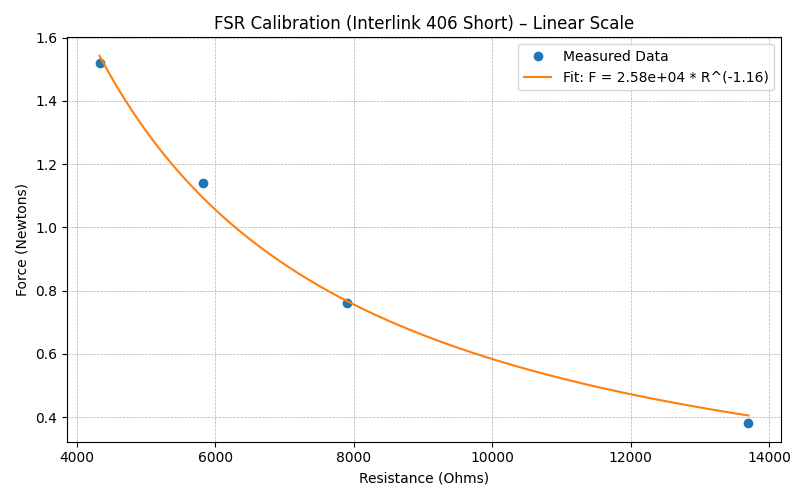
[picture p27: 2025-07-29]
Python_Code/Calibration1_Volt_Divider/Figure_2.png

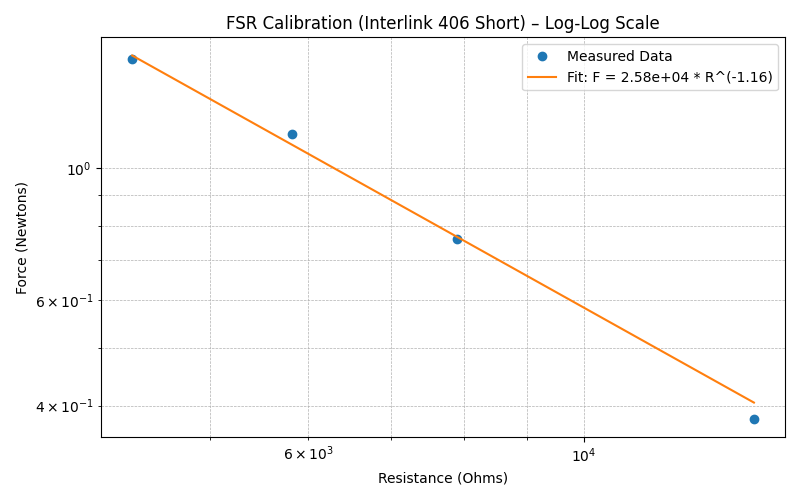
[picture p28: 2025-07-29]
Python_Code/Calibration1_Volt_Divider/Figure_1.png

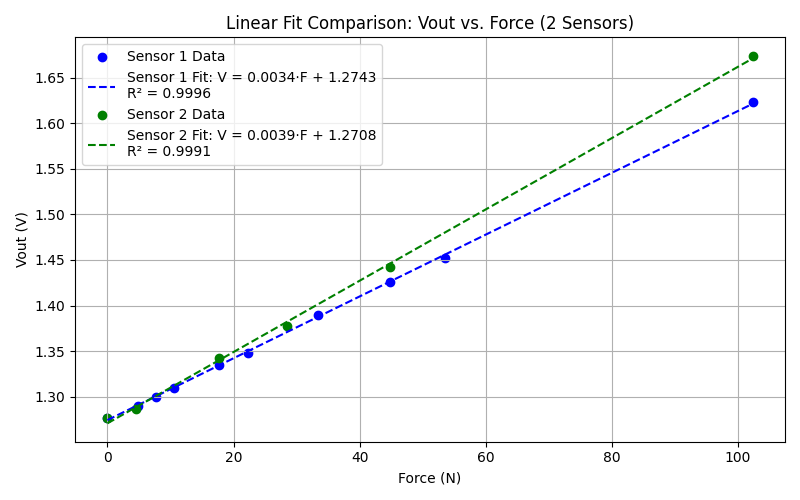
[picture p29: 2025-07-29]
Python_Code/Calibration2/Plots/Figure_4.png

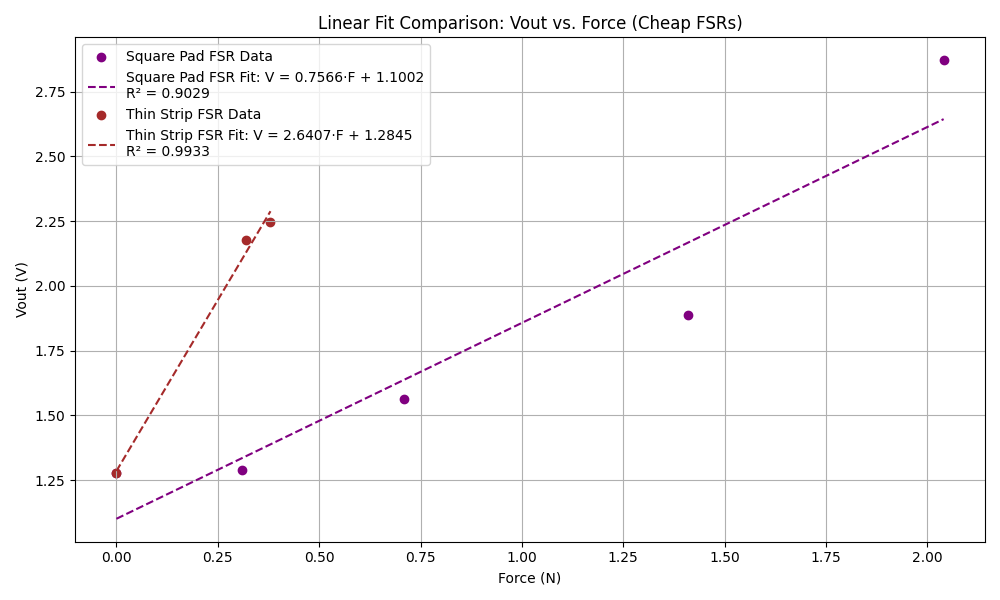
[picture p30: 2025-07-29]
Python_Code/Calibration2/Plots/Figure_7.png

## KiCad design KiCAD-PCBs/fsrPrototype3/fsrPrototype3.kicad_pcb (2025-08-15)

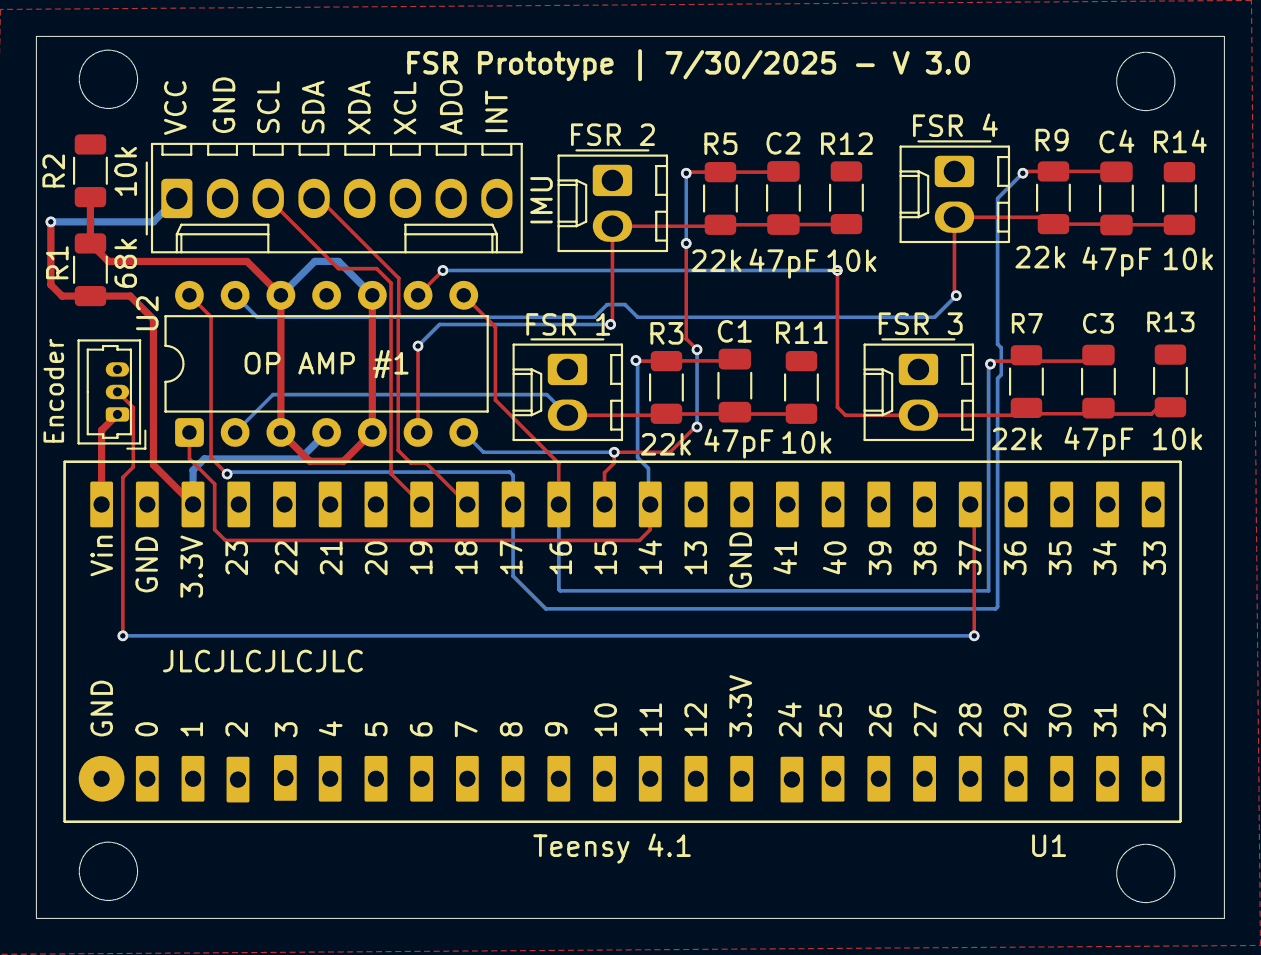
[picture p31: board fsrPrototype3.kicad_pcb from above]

Board: 2 copper layers, 66.0 x 49.0 mm, 22 parts (0 on the bottom side), 15 nets.

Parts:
C1, C2, C3, C4: 47pF; C_1206_3216Metric
Encoder: Conn_01x03; Molex_PicoBlade_53047-0310_1x03_P1.25mm_Vertical
FSR 1: FSR_1_Conn; Molex_KK-254_AE-6410-02A_1x02_P2.54mm_Vertical
FSR 2: FSR_2_Conn; Molex_KK-254_AE-6410-02A_1x02_P2.54mm_Vertical
FSR 3: FSR_3_Conn; Molex_KK-254_AE-6410-02A_1x02_P2.54mm_Vertical
FSR 4: FSR_4_Conn; Molex_KK-254_AE-6410-02A_1x02_P2.54mm_Vertical
IMU: Conn_01x08; Molex_KK-254_AE-6410-08A_1x08_P2.54mm_Vertical
R1: 68k; R_1206_3216Metric
R2, R11, R12, R13, R14: 10k; R_1206_3216Metric
R3, R5, R7, R9: 22k; R_1206_3216Metric
U1: Teensy4.1; Teensy_4.1
U2: MCP6004; DIP-14_W7.62mm

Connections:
GND: Encoder.3, FSR 1.1, FSR 2.1, FSR 3.1, FSR 4.1, IMU.2, R2.2, R11.1, R12.1, R13.1, R14.1, U1.1 (GND), U2.11 (V-)
unnamed: C1.1, FSR 1.2, R3.1, R11.2, U2.2 (-)
unnamed: C2.1, FSR 2.2, R5.1, R12.2, U2.6 (-)
unnamed: C3.1, FSR 3.2, R7.1, R13.2, U2.9 (-)
unnamed: C4.1, FSR 4.2, R9.1, R14.2, U2.13 (-)
unnamed: IMU.1, R1.1, U1.46 (3V3), U2.4 (V+)
unnamed: IMU.3, U1.41 (19_A5_SCL)
unnamed: IMU.4, U1.40 (18_A4_SDA)
unnamed: Encoder.1, U1.48 (VIN)
unnamed: Encoder.2, U1.29 (37_CS)
unnamed: C1.2, R3.2, U1.36 (14_A0_TX3_SPDIF_OUT), U2.1
unnamed: C2.2, R5.2, U1.37 (15_A1_RX3_SPDIF_IN), U2.7
unnamed: C3.2, R7.2, U1.38 (16_A2_RX4_SCL1), U2.8
unnamed: C4.2, R9.2, U1.39 (17_A3_TX4_SDA1), U2.14
unnamed: R1.2, R2.1, U2.3 (+), U2.5 (+), U2.10 (+), U2.12 (+)

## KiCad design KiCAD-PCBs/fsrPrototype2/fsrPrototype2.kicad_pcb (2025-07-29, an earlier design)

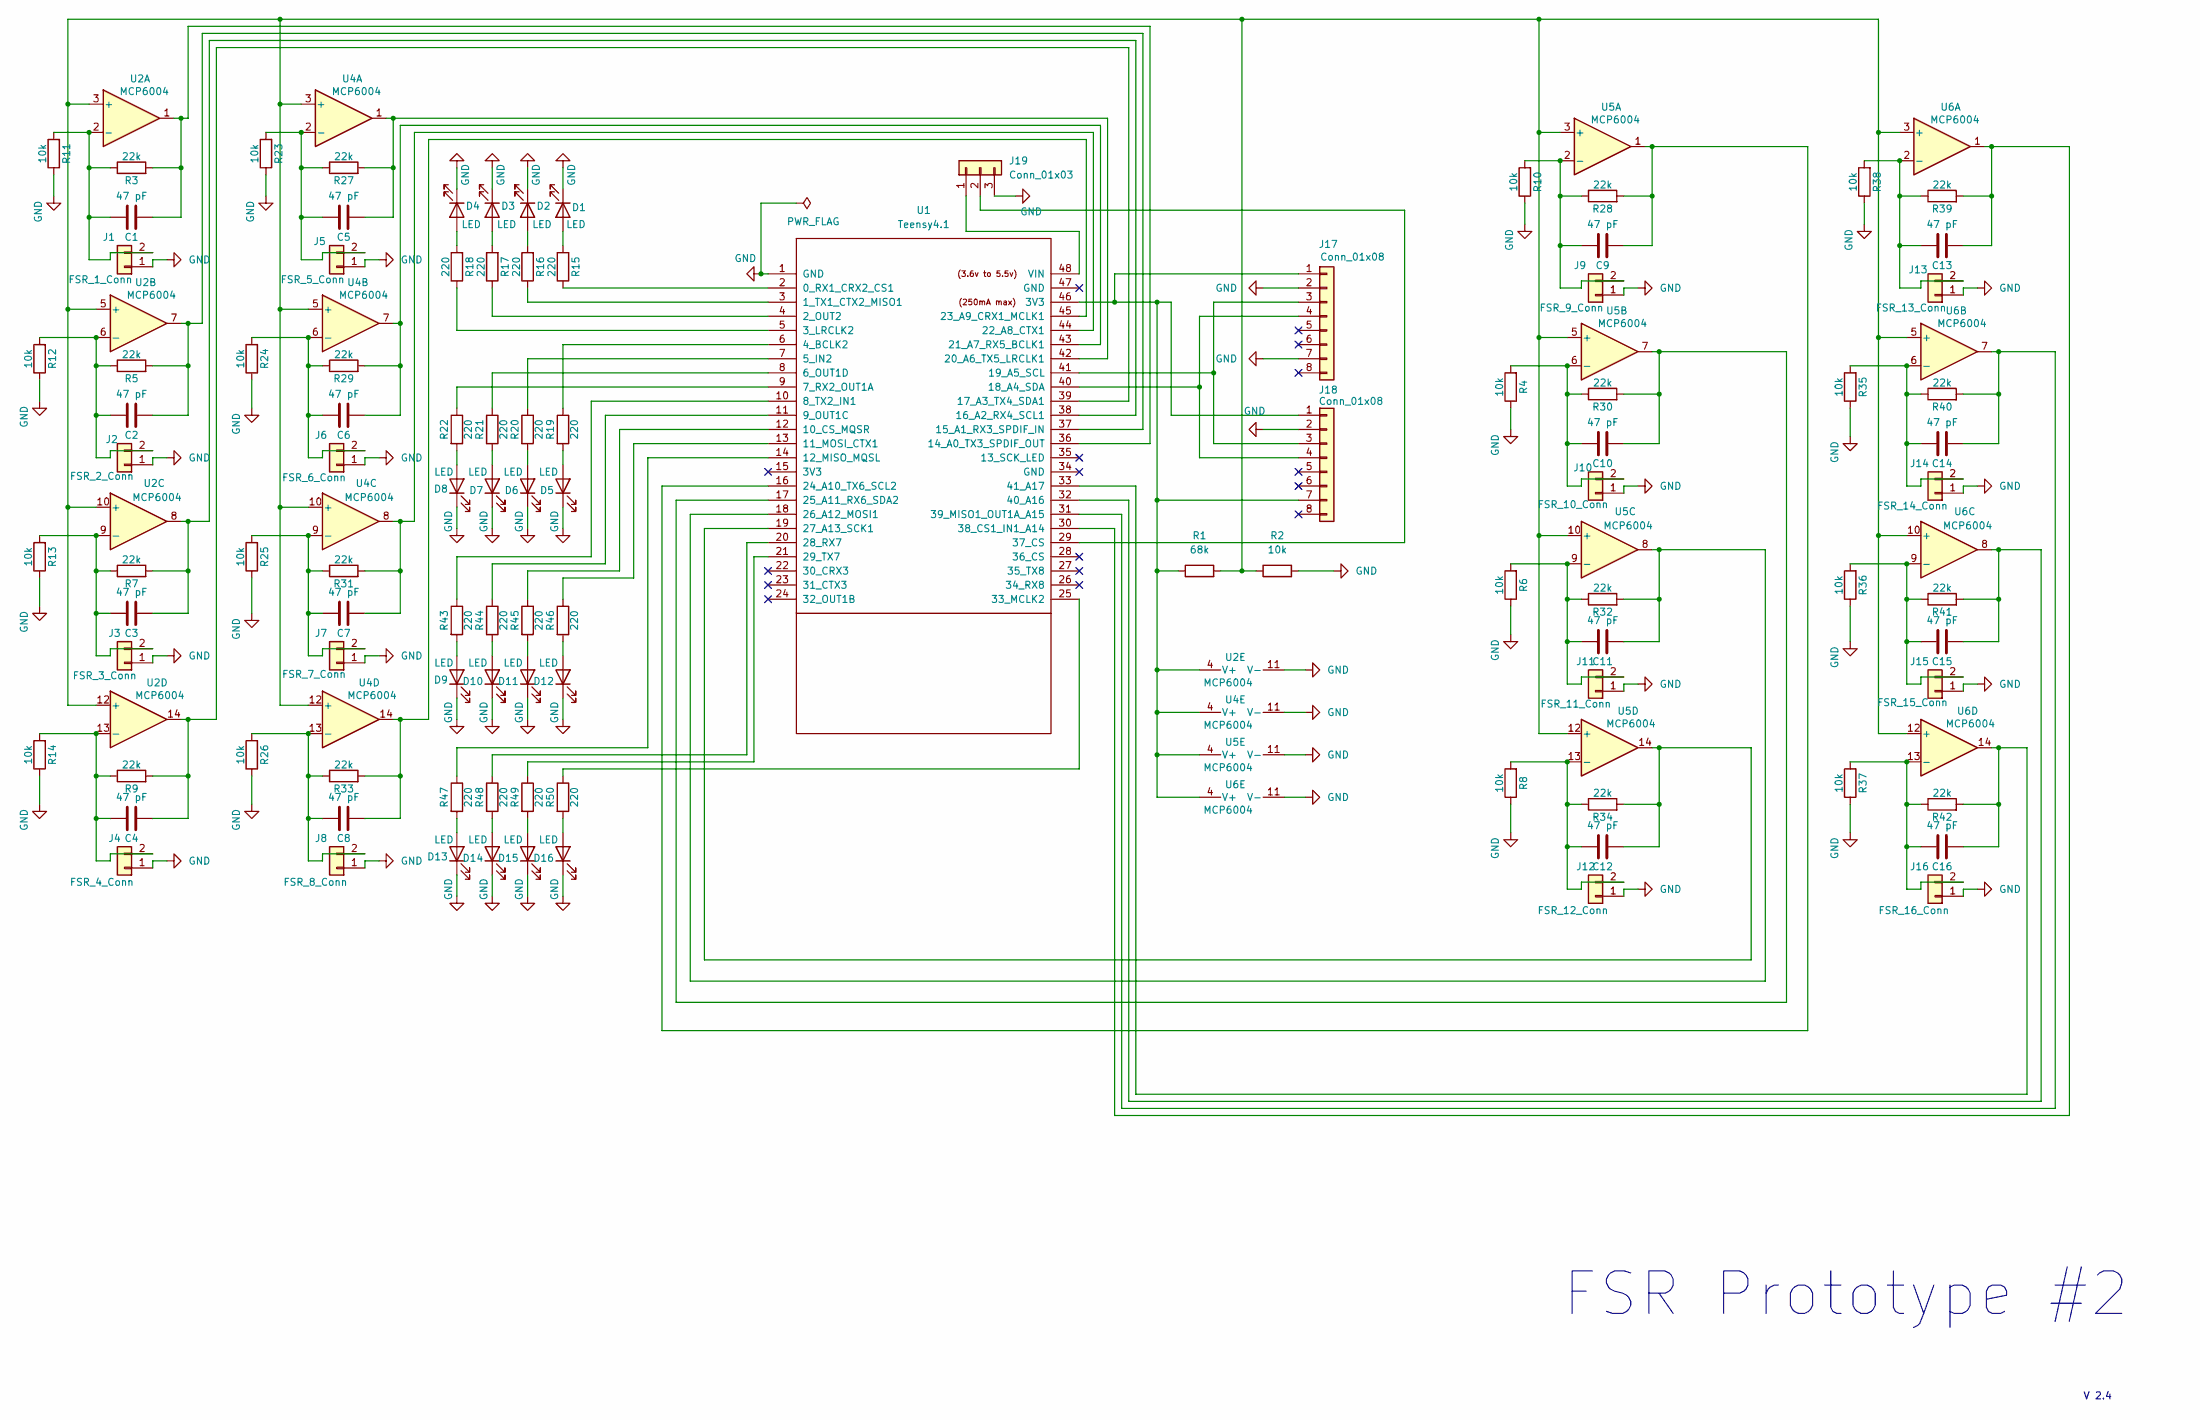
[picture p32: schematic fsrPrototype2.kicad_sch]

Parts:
C1, C2, C3, C4, C5, C6, C7, C8, C9, C10, C11, C12, C13, C14, C15, C16: 47 pF; C_1206_3216Metric
D1, D2, D3, D4, D5, D6, D7, D8, D9, D10, D11, D12, D13, D14, D15, D16: LED; LED_1206_3216Metric
J1: FSR_1_Conn; Molex_KK-254_AE-6410-02A_1x02_P2.54mm_Vertical
J2: FSR_2_Conn; Molex_KK-254_AE-6410-02A_1x02_P2.54mm_Vertical
J3: FSR_3_Conn; Molex_KK-254_AE-6410-02A_1x02_P2.54mm_Vertical
J4: FSR_4_Conn; Molex_KK-254_AE-6410-02A_1x02_P2.54mm_Vertical
J5: FSR_5_Conn; Molex_KK-254_AE-6410-02A_1x02_P2.54mm_Vertical
J6: FSR_6_Conn; Molex_KK-254_AE-6410-02A_1x02_P2.54mm_Vertical
J7: FSR_7_Conn; Molex_KK-254_AE-6410-02A_1x02_P2.54mm_Vertical
J8: FSR_8_Conn; Molex_KK-254_AE-6410-02A_1x02_P2.54mm_Vertical
J9: FSR_9_Conn; Molex_KK-254_AE-6410-02A_1x02_P2.54mm_Vertical
J10: FSR_10_Conn; Molex_KK-254_AE-6410-02A_1x02_P2.54mm_Vertical
J11: FSR_11_Conn; Molex_KK-254_AE-6410-02A_1x02_P2.54mm_Vertical
J12: FSR_12_Conn; Molex_KK-254_AE-6410-02A_1x02_P2.54mm_Vertical
J13: FSR_13_Conn; Molex_KK-254_AE-6410-02A_1x02_P2.54mm_Vertical
J14: FSR_14_Conn; Molex_KK-254_AE-6410-02A_1x02_P2.54mm_Vertical
J15: FSR_15_Conn; Molex_KK-254_AE-6410-02A_1x02_P2.54mm_Vertical
J16: FSR_16_Conn; Molex_KK-254_AE-6410-02A_1x02_P2.54mm_Vertical
J17, J18: Conn_01x08; Molex_KK-254_AE-6410-08A_1x08_P2.54mm_Vertical
J19: Conn_01x03; Molex_PicoBlade_53047-0310_1x03_P1.25mm_Vertical
R1: 68k; R_1206_3216Metric
R2, R4, R6, R8, R10, R11, R12, R13, R14, R23, R24, R25, R26, R35, R36, R37, R38: 10k; R_1206_3216Metric
R3, R5, R7, R9, R27, R28, R29, R30, R31, R32, R33, R34, R39, R40, R41, R42: 22k; R_1206_3216Metric
R15, R16, R17, R18, R19, R20, R21, R22, R43, R44, R45, R46, R47, R48, R49, R50: 220; R_1206_3216Metric
U1: Teensy4.1; Teensy_4.1
U2, U4, U5, U6: MCP6004; DIP-14_W7.62mm

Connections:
GND: D1.1 (K), D2.1 (K), D3.1 (K), D4.1 (K), D5.1 (K), D6.1 (K), D7.1 (K), D8.1 (K), D9.1 (K), D10.1 (K), D11.1 (K), D12.1 (K), D13.1 (K), D14.1 (K), D15.1 (K), D16.1 (K), J1.1, J2.1, J3.1, J4.1, J5.1, J6.1, J7.1, J8.1, J9.1, J10.1, J11.1, J12.1, J13.1, J14.1, J15.1, J16.1, J17.2, J17.7, J18.2, J19.3, R2.2, R4.1, R6.1, R8.1, R10.1, R11.1, R12.1, R13.1, R14.1, R23.1, R24.1, R25.1, R26.1, R35.1, R36.1, R37.1, R38.1, U1.1 (GND), U2.11 (V-), U4.11 (V-), U5.11 (V-), U6.11 (V-); also elsewhere on the board
unnamed: D1.2 (A), R15.2
unnamed: D2.2 (A), R16.2
unnamed: D3.2 (A), R17.2
unnamed: D4.2 (A), R18.2
unnamed: D5.2 (A), R19.2
unnamed: D6.2 (A), R20.2
unnamed: D7.2 (A), R21.2
unnamed: D8.2 (A), R22.2
unnamed: D9.2 (A), R43.2
unnamed: D10.2 (A), R44.2
unnamed: D11.2 (A), R45.2
unnamed: D12.2 (A), R46.2
unnamed: D13.2 (A), R47.2
unnamed: D14.2 (A), R48.2
unnamed: D15.2 (A), R49.2
unnamed: D16.2 (A), R50.2
unnamed: C1.1, J1.2, R3.1, R11.2, U2.2 (-)
unnamed: C2.1, J2.2, R5.1, R12.2, U2.6 (-)
unnamed: C3.1, J3.2, R7.1, R13.2, U2.9 (-)
unnamed: C4.1, J4.2, R9.1, R14.2, U2.13 (-)
unnamed: C5.1, J5.2, R23.2, R27.1, U4.2 (-)
unnamed: C6.1, J6.2, R24.2, R29.1, U4.6 (-)
unnamed: C7.1, J7.2, R25.2, R31.1, U4.9 (-)
unnamed: C8.1, J8.2, R26.2, R33.1, U4.13 (-)
unnamed: C9.1, J9.2, R10.2, R28.1, U5.2 (-)
unnamed: C10.1, J10.2, R4.2, R30.1, U5.6 (-)
unnamed: C11.1, J11.2, R6.2, R32.1, U5.9 (-)
unnamed: C12.1, J12.2, R8.2, R34.1, U5.13 (-)
unnamed: C13.1, J13.2, R38.2, R39.1, U6.2 (-)
unnamed: C14.1, J14.2, R35.2, R40.1, U6.6 (-)
unnamed: C15.1, J15.2, R36.2, R41.1, U6.9 (-)
unnamed: C16.1, J16.2, R37.2, R42.1, U6.13 (-)
unnamed 33: J17.1, J18.1, J18.7, R1.1, U1.46 (3V3), U2.4 (V+), U4.4 (V+), U5.4 (V+), U6.4 (V+); also elsewhere on the board
unnamed: J17.3, J18.3, U1.41 (19_A5_SCL)
unnamed: J17.4, J18.4, U1.40 (18_A4_SDA)
unnamed: J19.1, U1.48 (VIN)
unnamed: J19.2, U1.29 (37_CS)
unnamed: R15.1, U1.2 (0_RX1_CRX2_CS1)
unnamed: R16.1, U1.3 (1_TX1_CTX2_MISO1)
unnamed: R17.1, U1.4 (2_OUT2)
unnamed: R18.1, U1.5 (3_LRCLK2)
unnamed: R19.1, U1.6 (4_BCLK2)
unnamed: R20.1, U1.7 (5_IN2)
unnamed: R21.1, U1.8 (6_OUT1D)
unnamed: R22.1, U1.9 (7_RX2_OUT1A)
unnamed: R43.1, U1.10 (8_TX2_IN1)
unnamed: R44.1, U1.11 (9_OUT1C)
unnamed: R45.1, U1.12 (10_CS_MQSR)
unnamed: R46.1, U1.13 (11_MOSI_CTX1)
unnamed: R47.1, U1.14 (12_MISO_MQSL)
unnamed: C1.2, R3.2, U1.36 (14_A0_TX3_SPDIF_OUT), U2.1
unnamed: C2.2, R5.2, U1.37 (15_A1_RX3_SPDIF_IN), U2.7
unnamed: C3.2, R7.2, U1.38 (16_A2_RX4_SCL1), U2.8
unnamed: C4.2, R9.2, U1.39 (17_A3_TX4_SDA1), U2.14
unnamed: C5.2, R27.2, U1.42 (20_A6_TX5_LRCLK1), U4.1
unnamed: C6.2, R29.2, U1.43 (21_A7_RX5_BCLK1), U4.7
unnamed: C7.2, R31.2, U1.44 (22_A8_CTX1), U4.8
unnamed: C8.2, R33.2, U1.45 (23_A9_CRX1_MCLK1), U4.14
unnamed: C9.2, R28.2, U1.16 (24_A10_TX6_SCL2), U5.1
unnamed: C10.2, R30.2, U1.17 (25_A11_RX6_SDA2), U5.7
unnamed: C11.2, R32.2, U1.18 (26_A12_MOSI1), U5.8
unnamed: C12.2, R34.2, U1.19 (27_A13_SCK1), U5.14
unnamed: R48.1, U1.20 (28_RX7)
unnamed: R49.1, U1.21 (29_TX7)
unnamed: R50.1, U1.25 (33_MCLK2)
unnamed: C13.2, R39.2, U1.30 (38_CS1_IN1_A14), U6.1
unnamed: C14.2, R40.2, U1.31 (39_MISO1_OUT1A_A15), U6.7
unnamed: C15.2, R41.2, U1.32 (40_A16), U6.8
unnamed: C16.2, R42.2, U1.33 (41_A17), U6.14
unnamed 70: R1.2, R2.1, U2.3 (+), U2.5 (+), U2.10 (+), U2.12 (+), U4.3 (+), U4.5 (+), U4.10 (+), U4.12 (+), U5.3 (+), U5.5 (+), U5.10 (+), U5.12 (+), U6.3 (+), U6.5 (+), U6.10 (+), U6.12 (+); also elsewhere on the board

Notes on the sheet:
FSR Prototype #2
V 2.4

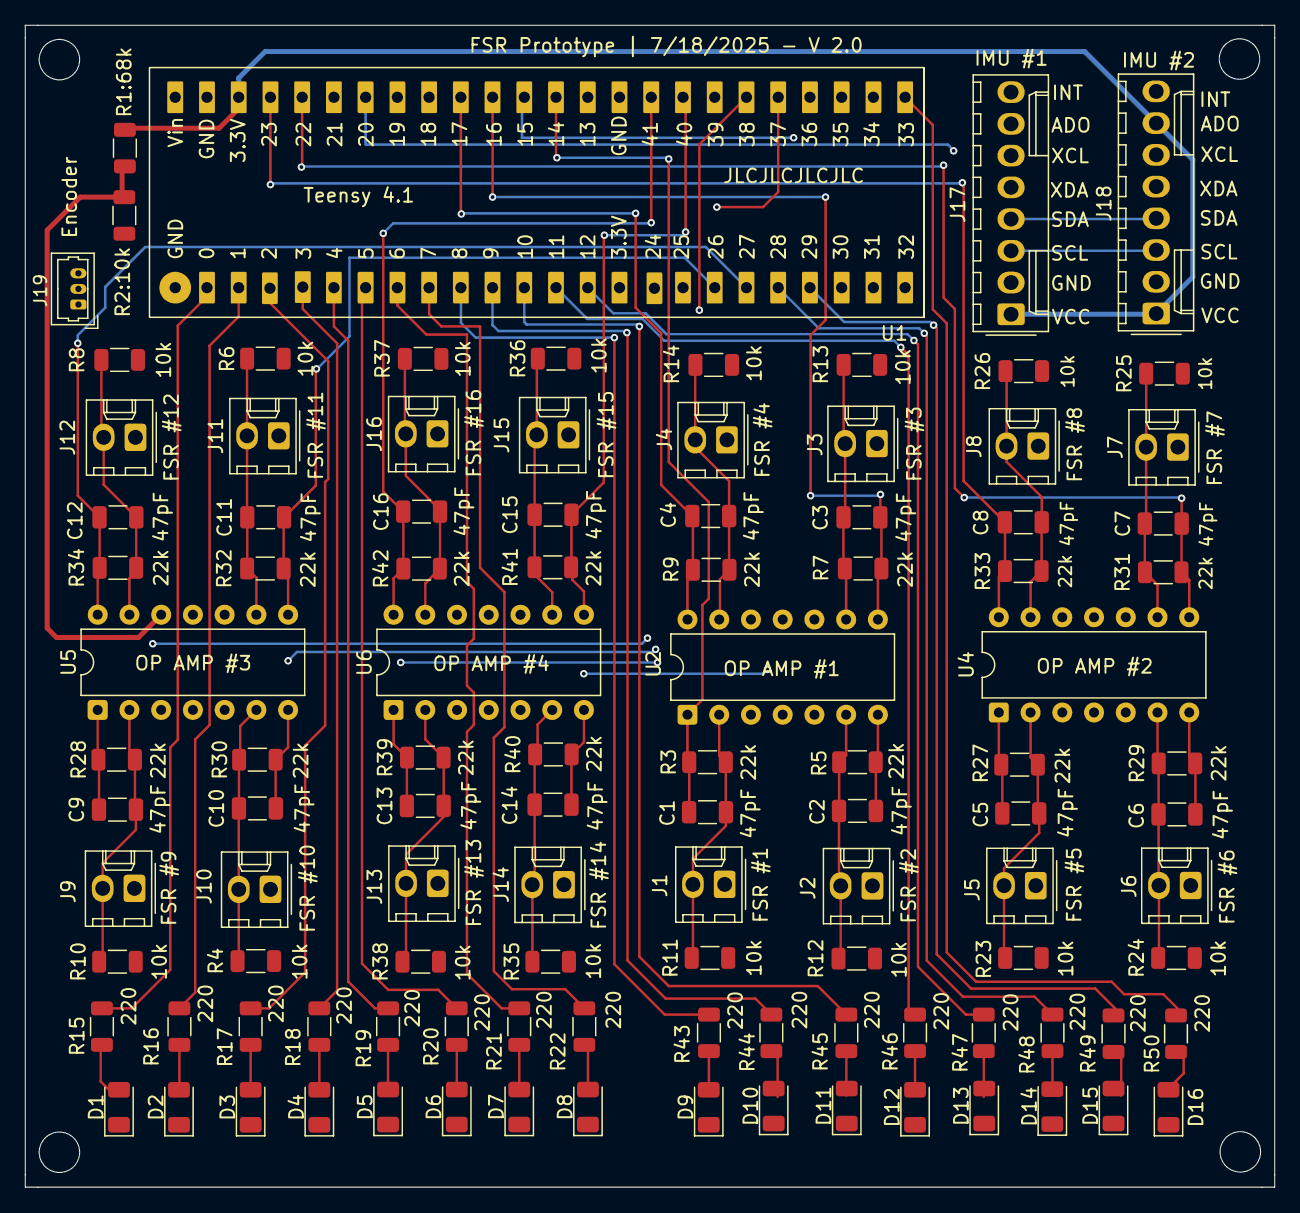
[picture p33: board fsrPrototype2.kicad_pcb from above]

Board: 4 copper layers, 100.0 x 93.0 mm, 106 parts (0 on the bottom side), 71 nets.

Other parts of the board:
R1:68k: 68k; R_1206_3216Metric
R2:10k: 10k; R_1206_3216Metric

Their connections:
GND: R2:10k.2; also elsewhere on the board
unnamed 33: R1:68k.1; also elsewhere on the board
unnamed 70: R1:68k.2, R2:10k.1; also elsewhere on the board

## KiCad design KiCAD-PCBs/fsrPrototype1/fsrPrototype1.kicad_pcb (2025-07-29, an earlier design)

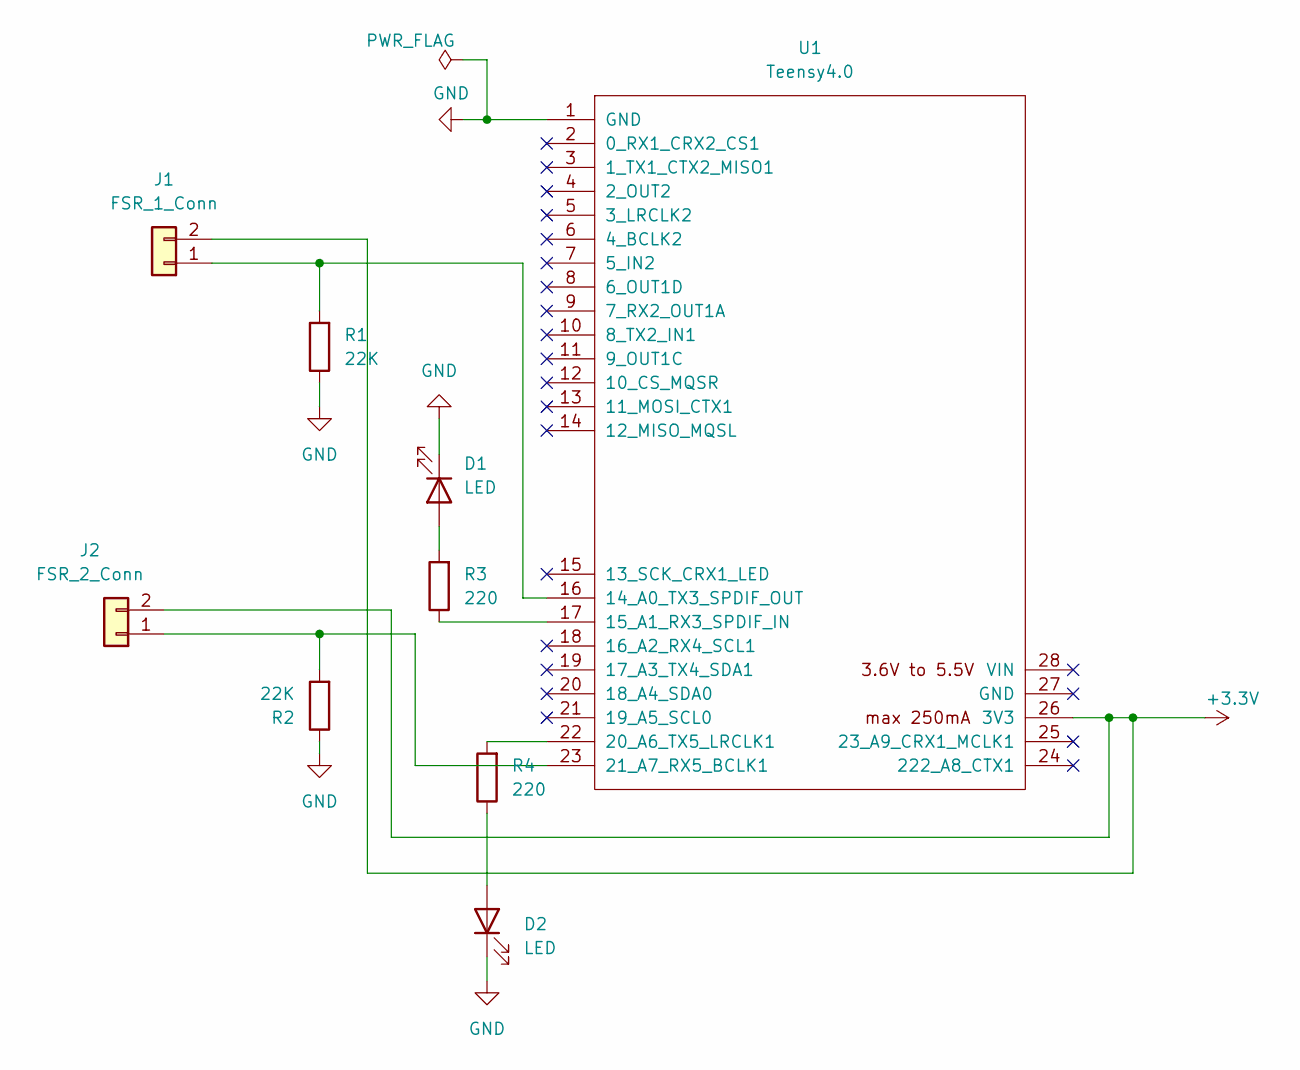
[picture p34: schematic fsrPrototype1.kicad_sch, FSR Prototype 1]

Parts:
D1, D2: LED; LED_1206_3216Metric
J1: FSR_1_Conn; Molex_KK-254_AE-6410-02A_1x02_P2.54mm_Vertical
J2: FSR_2_Conn; Molex_KK-254_AE-6410-02A_1x02_P2.54mm_Vertical
R1, R2: 22K; R_1206_3216Metric
R3, R4: 220; R_1206_3216Metric
U1: Teensy4.0; Teensy_4.0_Socketed

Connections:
+3.3V: J1.2, J2.2, U1.26 (3V3)
GND: D1.1 (K), D2.1 (K), R1.1, R2.1, U1.1 (GND)
unnamed: D1.2 (A), R3.2
unnamed: D2.2 (A), R4.1
unnamed: J1.1, R1.2, U1.16 (14_A0_TX3_SPDIF_OUT)
unnamed: J2.1, R2.2, U1.23 (21_A7_RX5_BCLK1)
unnamed: R3.1, U1.17 (15_A1_RX3_SPDIF_IN)
unnamed: R4.2, U1.22 (20_A6_TX5_LRCLK1)

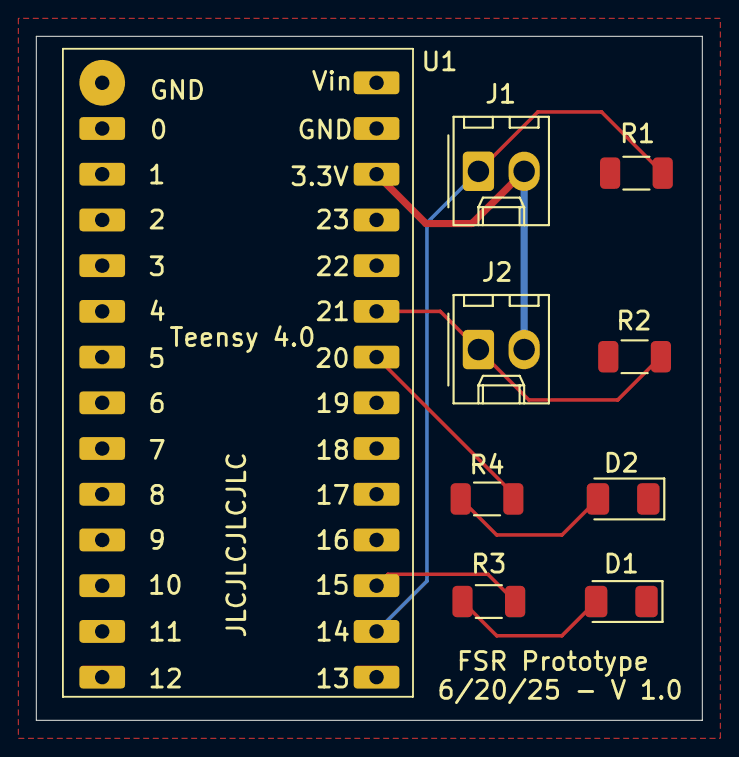
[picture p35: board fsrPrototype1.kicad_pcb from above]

Board: 2 copper layers, 37.0 x 38.0 mm, 9 parts (0 on the bottom side), 8 nets.

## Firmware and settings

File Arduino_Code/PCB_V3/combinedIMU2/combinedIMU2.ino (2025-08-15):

//
// MPU-6050 Mahony IMU  (yaw angle is relative to starting orientation)
// last update 7/9/2020 
//

#include <Adafruit_MPU6050.h>
#include <Adafruit_Sensor.h>
#include "Wire.h"

Adafruit_MPU6050 mpu;

// AD0 low = 0x68 (default for Sparkfun module)
// AD0 high = 0x69
int MPU_addr = 0x68;

// vvvvvvvvvvvvvvvvvv  VERY VERY IMPORTANT vvvvvvvvvvvvvvvvvvvvvvvvvvvvv
//These are the previously determined offsets and scale factors for accelerometer and gyro for
// a particular example of an MPU-6050. They are not correct for other examples.
//The IMU code will NOT work well or at all if these are not correct

float A_cal[6] = {265.0, -80.0, -700.0, 0.994, 1.000, 1.014}; // 0..2 offset xyz, 3..5 scale xyz
float G_off[3] = { -499.5, -17.7, -82.0}; //raw offsets, determined for gyro at rest
#define gscale ((250./32768.0)*(PI/180.0))  //gyro default 250 LSB per d/s -> rad/s

// ^^^^^^^^^^^^^^^^^^^ VERY VERY IMPORTANT ^^^^^^^^^^^^^^^^^^^^^^^^^^^^^^

// GLOBALLY DECLARED, required for Mahony filter
// vector to hold quaternion
float q[4] = {1.0, 0.0, 0.0, 0.0};

// Free parameters in the Mahony filter and fusion scheme,
// Kp for proportional feedback, Ki for integral
float Kp = 30.0;
float Ki = 0.0;

// globals for AHRS loop timing
unsigned long now_ms, last_ms = 0; //millis() timers

// print interval
unsigned long print_ms = 200; //print angles every "print_ms" milliseconds
float yaw, pitch, roll; //Euler angle output

void setup() {

  Wire.begin();                 // ensure I2C up before any access
  Wire.setClock(400000);        // 400 kHz Fast-mode
  Wire.setTimeout(5);           // short timeout to avoid hangs

  Serial.begin(9600);
  unsigned long t0 = millis();
  while (!Serial && millis() - t0 < 2000) { /* brief wait */ }
  Serial.println("starting");

  // Wake the MPU via register-level path
  Wire.beginTransmission(MPU_addr);
  Wire.write(0x6B);  // PWR_MGMT_1 register
  Wire.write(0);     // wake
  Wire.endTransmission(true);

  // Initialize Adafruit driver (retry instead of hang)
  int tries = 0;
  while (!mpu.begin()) {
    Serial.println("Failed to find MPU6050 chip, retrying...");
    delay(200);
    if (++tries > 20) {
      Serial.println("Proceeding without Adafruit driver initialized.");
      break;
    }
  }
  if (tries <= 20) {
    mpu.setAccelerometerRange(MPU6050_RANGE_8_G);
    Serial.print("Accelerometer range set to: ");
    switch (mpu.getAccelerometerRange()) {
    case MPU6050_RANGE_2_G:  Serial.println("+-2G"); break;
    case MPU6050_RANGE_4_G:  Serial.println("+-4G"); break;
    case MPU6050_RANGE_8_G:  Serial.println("+-8G"); break;
    case MPU6050_RANGE_16_G: Serial.println("+-16G"); break;
    }
    mpu.setGyroRange(MPU6050_RANGE_500_DEG);
    Serial.print("Gyro range set to: ");
    switch (mpu.getGyroRange()) {
    case MPU6050_RANGE_250_DEG:  Serial.println("+- 250 deg/s"); break;
    case MPU6050_RANGE_500_DEG:  Serial.println("+- 500 deg/s"); break;
    case MPU6050_RANGE_1000_DEG: Serial.println("+- 1000 deg/s"); break;
    case MPU6050_RANGE_2000_DEG: Serial.println("+- 2000 deg/s"); break;
    }

    mpu.setFilterBandwidth(MPU6050_BAND_21_HZ);
    Serial.print("Filter bandwidth set to: ");
    switch (mpu.getFilterBandwidth()) {
    case MPU6050_BAND_260_HZ: Serial.println("260 Hz"); break;
    case MPU6050_BAND_184_HZ: Serial.println("184 Hz"); break;
    case MPU6050_BAND_94_HZ:  Serial.println("94 Hz"); break;
    case MPU6050_BAND_44_HZ:  Serial.println("44 Hz"); break;
    case MPU6050_BAND_21_HZ:  Serial.println("21 Hz"); break;
    case MPU6050_BAND_10_HZ:  Serial.println("10 Hz"); break;
    case MPU6050_BAND_5_HZ:   Serial.println("5 Hz"); break;
    }
  }

  Serial.println("");
  delay(100);
}

// AHRS loop

void loop()
{
  /* Get new sensor events with the readings */
  sensors_event_t a, g, temp;
  static bool adafruit_ok = true;  // assume ok after setup; adjust if needed
  if (adafruit_ok) {
    mpu.getEvent(&a, &g, &temp);
  }

  static int i = 0;
  static float deltat = 0;  //loop time in seconds
  static unsigned long now = 0, last = 0; //micros() timers

  //raw data containers
  int16_t ax, ay, az;
  int16_t gx, gy, gz;
  int16_t Tmp; //temperature

  //scaled data as vector
  float Axyz[3];
  float Gxyz[3];

  // ---- Robust raw read with availability guard (no goto) ----
  bool ok = true;

  if (ok) {
    Wire.beginTransmission(MPU_addr);
    Wire.write(0x3B);  // ACCEL_XOUT_H
    if (Wire.endTransmission(false) != 0) ok = false;
  }

  if (ok) {
    if (Wire.requestFrom(MPU_addr, 14, true) != 14) ok = false;
  }

  if (ok) {
    int t = Wire.read() << 8; ax = t | Wire.read();
    t = Wire.read() << 8;     ay = t | Wire.read();
    t = Wire.read() << 8;     az = t | Wire.read();
    t = Wire.read() << 8;     Tmp = t | Wire.read(); // temp
    t = Wire.read() << 8;     gx = t | Wire.read();
    t = Wire.read() << 8;     gy = t | Wire.read();
    t = Wire.read() << 8;     gz = t | Wire.read();

    Axyz[0] = (float) ax;
    Axyz[1] = (float) ay;
    Axyz[2] = (float) az;

    //apply offsets and scale factors from Magneto
    for (int i = 0; i < 3; i++) Axyz[i] = (Axyz[i] - A_cal[i]) * A_cal[i + 3];

    Gxyz[0] = ((float) gx - G_off[0]) * gscale; // rad/s
    Gxyz[1] = ((float) gy - G_off[1]) * gscale;
    Gxyz[2] = ((float) gz - G_off[2]) * gscale;

    now = micros();
    deltat = (now - last) * 1.0e-6; //seconds since last update
    last = now;

    Mahony_update(Axyz[0], Axyz[1], Axyz[2], Gxyz[0], Gxyz[1], Gxyz[2], deltat);

    // Compute Tait-Bryan angles.
    roll  = atan2((q[0] * q[1] + q[2] * q[3]), 0.5 - (q[1] * q[1] + q[2] * q[2]));
    pitch = asin(2.0 * (q[0] * q[2] - q[1] * q[3]));
    // conventional yaw increases clockwise from North
    yaw   = -atan2((q[1] * q[2] + q[0] * q[3]), 0.5 - (q[2] * q[2] + q[3] * q[3]));
    // to degrees
    yaw   *= 180.0 / PI; if (yaw < 0) yaw += 360.0;
    pitch *= 180.0 / PI;
    roll  *= 180.0 / PI;
  }

  // ---- Print section (unchanged formatting) ----
  now_ms = millis(); //time to print?
  if (now_ms - last_ms >= print_ms) {
    last_ms = now_ms;

    // Print quaternion first
    Serial.print("q: ");
    Serial.print(q[0], 6); Serial.print(", ");
    Serial.print(q[1], 6); Serial.print(", ");
    Serial.print(q[2], 6); Serial.print(", ");
    Serial.print(q[3], 6);
    Serial.print("   ");

    // Then print Euler angles (yaw, pitch, roll)
    Serial.print("ypr: ");
    Serial.print(yaw, 0);   Serial.print(", ");
    Serial.print(pitch, 0); Serial.print(", ");
    Serial.println(roll, 0);
    Serial.print("   ");

    if (adafruit_ok) {
      Serial.print("Rotation X: ");
      Serial.print(g.gyro.x);
      Serial.print(", Y: ");
      Serial.print(g.gyro.y);
      Serial.print(", Z: ");
      Serial.print(g.gyro.z);
      Serial.println(" rad/s");

      Serial.print("Temperature: ");
      Serial.print(temp.temperature);
      Serial.println(" degC");
    }
  }
}
//--------------------------------------------------------------------------------------------------
// Mahony scheme uses proportional and integral filtering on
// the error between estimated reference vector (gravity) and measured one.
// Madgwick's implementation of Mayhony's AHRS algorithm.
// See: http://www.x-io.co.uk/node/8#open_source_ahrs_and_imu_algorithms
//
// Date      Author      Notes
// 29/09/2011 SOH Madgwick    Initial release
// 02/10/2011 SOH Madgwick  Optimised for reduced CPU load
// last update 07/09/2020 SJR minor edits
//--------------------------------------------------------------------------------------------------
// IMU algorithm update

void Mahony_update(float ax, float ay, float az, float gx, float gy, float gz, float deltat) {
  float recipNorm;
  float vx, vy, vz;
  float ex, ey, ez;  //error terms
  float qa, qb, qc;
  static float ix = 0.0, iy = 0.0, iz = 0.0;  //integral feedback terms
  float tmp;

  // Compute feedback only if accelerometer measurement valid (avoids NaN in accelerometer normalisation)
  tmp = ax * ax + ay * ay + az * az;
  if (tmp > 0.0)
  {

    // Normalise accelerometer (assumed to measure the direction of gravity in body frame)
    recipNorm = 1.0 / sqrt(tmp);
    ax *= recipNorm;
    ay *= recipNorm;
    az *= recipNorm;

    // Estimated direction of gravity in the body frame (factor of two divided out)
    vx = q[1] * q[3] - q[0] * q[2];
    vy = q[0] * q[1] + q[2] * q[3];
    vz = q[0] * q[0] - 0.5f + q[3] * q[3];

    // Error is cross product between estimated and measured direction of gravity in body frame
    // (half the actual magnitude)
    ex = (ay * vz - az * vy);
    ey = (az * vx - ax * vz);
    ez = (ax * vy - ay * vx);

    // Compute and apply to gyro term the integral feedback, if enabled
    if (Ki > 0.0f) {
      ix += Ki * ex * deltat;  // integral error scaled by Ki
      iy += Ki * ey * deltat;
      iz += Ki * ez * deltat;
      gx += ix;  // apply integral feedback
      gy += iy;
      gz += iz;
    }

    // Apply proportional feedback to gyro term
    gx += Kp * ex;
    gy += Kp * ey;
    gz += Kp * ez;
  }

  // Integrate rate of change of quaternion, q cross gyro term
  deltat = 0.5 * deltat;
  gx *= deltat;   // pre-multiply common factors
  gy *= deltat;
  gz *= deltat;
  qa = q[0];
  qb = q[1];
  qc = q[2];
  q[0] += (-qb * gx - qc * gy - q[3] * gz);
  q[1] += (qa * gx + qc * gz - q[3] * gy);
  q[2] += (qa * gy - qb * gz + q[3] * gx);
  q[3] += (qa * gz + qb * gy - qc * gx);

  // renormalise quaternion
  recipNorm = 1.0 / sqrt(q[0] * q[0] + q[1] * q[1] + q[2] * q[2] + q[3] * q[3]);
  q[0] = q[0] * recipNorm;
  q[1] = q[1] * recipNorm;
  q[2] = q[2] * recipNorm;
  q[3] = q[3] * recipNorm;
}

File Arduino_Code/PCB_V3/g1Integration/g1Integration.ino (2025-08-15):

// Teensy/Arduino 1000 Hz logger for 4x FSR + MPU-6050 + Madgwick
#include <Wire.h>
#include <MadgwickAHRS.h>

// ===================== FSRs =====================
const int   analogPins[4]   = {A0, A1, A2, A3};
const char* analogNames[4]  = {"FSR1", "FSR2", "FSR3", "FSR4"};
const float Vcc             = 3.3f;
// Force [N] = slope * Vout + intercept
const float slope[4]        = {308.010f, 252.743f, 232.058f, 236.940f};
const float intercept[4]    = {-413.037f, -339.549f, -313.218f, -319.241f};

// ===================== IMU (MPU-6050) =====================
const uint8_t MPU_ADDR = 0x68;   // AD0 = GND
Madgwick filter;

// Gyro bias (deg/s)
float gx_off = 0, gy_off = 0, gz_off = 0;
// For angular accel derivative (deg/s to deg/s^2)
float prev_gx = 0, prev_gy = 0, prev_gz = 0;
float angAccX = 0, angAccY = 0, angAccZ = 0;  // EMA-smoothed (deg/s^2)
const float kalmanK = 0.2f;                   // EMA factor for ang. accel smoothing

// ===================== Loop timing =====================
// Fixed 1000 Hz loop (1 ms tick)
const uint32_t LOOP_US = 1000;
uint32_t nextTick = 0;   // micros() timestamp of next tick

// ===================== Logging Control =====================
bool logging = false;
bool headerPrinted = false;
unsigned long t0_ms = 0;
const uint16_t PRINT_EVERY_N = 1;   // 1 = print every sample (~1000 Hz). Bump to 10 for ~100 Hz.
uint32_t sampleCount = 0;

// ---------- IMU helpers ----------
void i2cWriteByte(uint8_t addr, uint8_t reg, uint8_t val) {
  Wire.beginTransmission(addr);
  Wire.write(reg);
  Wire.write(val);
  Wire.endTransmission();
}

uint8_t i2cReadByte(uint8_t addr, uint8_t reg) {
  Wire.beginTransmission(addr);
  Wire.write(reg);
  Wire.endTransmission(false);
  Wire.requestFrom(addr, (uint8_t)1);
  return Wire.available() ? Wire.read() : 0;
}

void wakeMPU(uint8_t addr) {
  // PWR_MGMT_1: clear sleep
  i2cWriteByte(addr, 0x6B, 0x00);
  delay(100);
}

void configureMPU_1kHz(uint8_t addr) {
  // CONFIG (0x1A): DLPF_CFG = 0 (260 Hz gyro BW, 1 kHz sample rate)
  i2cWriteByte(addr, 0x1A, 0x00);
  // SMPLRT_DIV (0x19): with DLPF on, base is 1 kHz; divider=0 -> 1 kHz
  i2cWriteByte(addr, 0x19, 0x00);
  // GYRO_CONFIG (0x1B): FS_SEL=0 (±250 dps => 131 LSB/(deg/s))
  i2cWriteByte(addr, 0x1B, 0x00);
  // ACCEL_CONFIG (0x1C): AFS_SEL=0 (±2 g => 16384 LSB/g)
  i2cWriteByte(addr, 0x1C, 0x00);
  delay(50);
}

void readRaw(uint8_t addr, int16_t &ax, int16_t &ay, int16_t &az,
                        int16_t &gx, int16_t &gy, int16_t &gz) {
  Wire.beginTransmission(addr);
  Wire.write(0x3B); // ACCEL_XOUT_H
  Wire.endTransmission(false);
  Wire.requestFrom(addr, (uint8_t)14);
  if (Wire.available() >= 14) {
    ax = (Wire.read() << 8) | Wire.read();
    ay = (Wire.read() << 8) | Wire.read();
    az = (Wire.read() << 8) | Wire.read();
    Wire.read(); Wire.read(); // TEMP (skip)
    gx = (Wire.read() << 8) | Wire.read();
    gy = (Wire.read() << 8) | Wire.read();
    gz = (Wire.read() << 8) | Wire.read();
  }
}

// GYRO-ONLY calibration: estimate gyro biases (deg/s). Do NOT change accelerometer.
void calibrateGyro(uint8_t addr, float &gx_off, float &gy_off, float &gz_off) {
  const int samples = 2000;
  long sum_gx = 0, sum_gy = 0, sum_gz = 0;

  for (int i = 0; i < samples; i++) {
    int16_t ax, ay, az, gx, gy, gz;
    readRaw(addr, ax, ay, az, gx, gy, gz);
    sum_gx += gx; sum_gy += gy; sum_gz += gz;
    delayMicroseconds(500); // quicker calibration but still averages motion-free bias
  }
  gx_off = (sum_gx / (float)samples) / 131.0f;
  gy_off = (sum_gy / (float)samples) / 131.0f;
  gz_off = (sum_gz / (float)samples) / 131.0f;
}

// ===================== Arduino =====================
void setup() {
  // High baud to sustain ~kHz CSV
  Serial.begin(2000000);
  while (!Serial) { /* wait for USB */ }

  // ADC resolution matches scaling (0..1023)
  analogReadResolution(10);

  // I2C for IMU at 400 kHz (MPU-6050 limit)
  Wire.setSDA(18); Wire.setSCL(19);
  Wire.begin();
  Wire.setClock(400000);

  wakeMPU(MPU_ADDR);
  configureMPU_1kHz(MPU_ADDR);
  calibrateGyro(MPU_ADDR, gx_off, gy_off, gz_off);

  // Madgwick nominal sample rate = 1000 Hz
  filter.begin(1000.0f);

  nextTick = micros() + LOOP_US;

  Serial.println("Ready. Type 's' + Enter to START logging CSV; type 'x' + Enter to STOP.");
  Serial.println("(Sensors run at 1000 Hz. Use PRINT_EVERY_N to decimate prints if needed.)");
}

void maybeHandleSerialCommands() {
  while (Serial.available() > 0) {
    int c = Serial.read();
    if (c == 's' || c == 'S') {
      logging = true;
      headerPrinted = false;   // will print header at next print
      t0_ms = millis();        // reset time zero on start
      sampleCount = 0;
    } else if (c == 'x' || c == 'X') {
      logging = false;
    }
  }
}

void readFSR_Forces(float forces_out[4]) {
  for (int i = 0; i < 4; i++) {
    int raw = analogRead(analogPins[i]);
    float Vout = raw * (Vcc / 1023.0f);
    float Force = slope[i] * Vout + intercept[i];
    if (Force < 0.0f) Force = 0.0f;      // clip negatives
    if (Force < 2.0f) Force = 0.0f;      // deadzone below 2 N
    forces_out[i] = Force;
  }
}
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

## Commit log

2025-07-29 Add files via upload
    initial CAD prototype for sandwich structure
    [141_PV2S240xx.SLDPRT, A201.SLDPRT, A201_Puck.SLDASM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]
2025-07-29 Add files via upload
    Passive toe mechanism version 1 CAD
    [2867T41_Corrosion-Resistant Sleeve Bearing.SLDPRT, 57155K356_Stainless Steel Ball Bearing.SLDPRT, 6436K32_Clamping Two-Piece Shaft Collar.SLDPRT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]
2025-07-29 Add files via upload
    Passive toe mechanism V2 with integrated sensors CAD
    [10x_FLXLC-A.STL, 2867T41_Corrosion-Resistant Sleeve Bearing.SLDPRT, 2x_A401_Puck.STL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]
2025-07-29 Add files via upload
    Initial CAD for integrating sensors onto G1 humanoid foot
    [90751A110_18-8 Stainless Steel Socket Head Screws.SLDPRT, Assem1.SLDASM, cleanToe.SLDPRT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]
2025-07-29 PCB Prototype V1
    KiCAD / Gerber files for initial PCB with 2 FSRs, 2 LEDs, and a Teensy 4.0
    [fsrPrototype1-B_Mask.gbs, fsrPrototype1-B_Paste.gbp, fsrPrototype1-B_Silkscreen.gbo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]
2025-07-29 PCB Prototype 2
    KiCAD / Gerber files for PCB prototype 2 with 4 op amps, 16 FSRs, 16 LEDs, encoder, 2 IMUs, and a Teensy 4.1
    [fsrPrototype2-B_Mask.gbs, fsrPrototype2-B_Paste.gbp, fsrPrototype2-B_Silkscreen.gbo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]
2025-07-29 Python code for calibration
    Python scripts & notebooks to calibrate sensors and analyze their data
    [fsr_a502_differences.csv, fsr_fit_differences.csv]
2025-07-29 Created hierarchical folders
    [10x_FLXLC-A.STL, 141_PV2S240xx.SLDPRT, 2867T41_Corrosion-Resistant Sleeve Bearing.SLDPRT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]
2025-08-15 updated project files from SURF
    [10x_longSpacer.STL, 16_spacer3.STL, 8x_FLXLC-A.STL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]
